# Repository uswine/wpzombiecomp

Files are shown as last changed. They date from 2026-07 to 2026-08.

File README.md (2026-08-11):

# Offset Smoker — Door Spring-Hinge Assembly

Design proposal for the main cook-chamber doors: a **cam-detent snap-close** combined
with **coiled-ribbon (power spring) lift assist**, with all spring hardware mounted
outboard of the shell behind a heat shield.

Behavior over the 90° door travel:
- **0–15°** — cam detent pulls the door shut with authority and holds it sealed
- **15–88°** — ribbon springs carry ~73% of the door weight (peak hand effort ~11 lb
  instead of 37 lb on the worked example)
- **88–90°** — a shallow second cam notch parks the door vertical

| File | Contents |
|---|---|
| [`docs/PHONE-SETUP.md`](docs/PHONE-SETUP.md) | How to run Claude Code sessions on this repo from a phone, and how to create new repositories for it |
| [`docs/DESIGN.md`](docs/DESIGN.md) | Full proposal: concept, torque analysis, component specs, tuning procedure, alternatives comparison |
| [`drawings/`](drawings/) | Blueprint sheets 1–4: assembly end view, snap cam detail, spring canister section, torque-balance chart |
| [`calculator.html`](calculator.html) | Interactive sizing calculator — re-solves springs, cam, and stall check for your actual chamber/door dimensions (works offline) |
| [`tools/generate_drawings.py`](tools/generate_drawings.py) | Generates the SVG sheets from the design parameters |
| [`docs/PLATE-OPTIMIZATION.md`](docs/PLATE-OPTIMIZATION.md) | Rotary damper plates (Rev B): sealing rules, architecture trade study, optimization record |
| [`drawings/plate-24-perforated.*`](drawings/) | Waterjet fabrication print (SVG/PDF) + cut-ready DXF — Ø24 damper plate, QTY 2 identical |
| [`tools/generate_plate_drawing.py`](tools/generate_plate_drawing.py) | Generates the damper plate print and DXF |
| [`drawings/pizza-plate-24.*`](drawings/) | 24" pizza cooking plate (vertical smoker): fab print (SVG/PDF), single-contour DXF, STL solid |
| [`mail-sender/`](mail-sender/) | Outbound email API for Claude sessions: send as ahall@zombiecomponents.com via Microsoft Graph (app-only flow, one-mailbox scoped) |
| [`tools/generate_pizza_plate.py`](tools/generate_pizza_plate.py) | Parametric generator for the pizza plate (contour, DXF, STL, print) |

The worked example assumes a 24" OD × ¼"-wall chamber with a 120° × 30" top-hinged
door; every number is parametric — see `docs/DESIGN.md` §4 or plug real dimensions
into the calculator.

Sheet 1 — Assembly

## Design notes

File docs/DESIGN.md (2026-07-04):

# Offset Smoker — Door Spring-Hinge Assembly
### Cam-detent snap-close + coiled ribbon (power spring) lift assist

**Status:** Design proposal for review
**Drawings:** `drawings/sheet1-assembly.svg` … `sheet4-torque.svg`
**Sizing tool:** `calculator.html` (open in any browser, works offline)

> **Note on dimensions.** The earlier blueprint work isn't in this repository, so the
> worked example below assumes a typical 24" OD × ¼"-wall pipe cook chamber with a
> 120°-arc × 30"-long top-hinged door (~60 lb). Every number derives from the formulas
> in §4, and `calculator.html` re-solves the whole design for your actual chamber
> diameter, door arc, and door length — plug in the real blueprint dimensions and it
> outputs the spring and cam specs directly.

---

## 1. What the mechanism does

Three distinct behaviors over the 90° door travel, exactly as requested:

| Zone | Door angle | Behavior | What provides it |
|---|---|---|---|
| **Snap zone** | 0°–15° | Door is pulled shut with authority and held sealed (~105 in·lb net closing at the seat) | Cam detent valley + spring-loaded roller follower |
| **Assist zone** | 15°–88° | Ribbon springs carry ~70–75% of the door weight; peak hand effort ≈ **11 lb** instead of **37 lb** bare | Two power-spring canisters on the hinge shaft |
| **Hold-open** | 88°–90° | Door parks vertical with ~2× holding margin; a light tug releases it | Shallow second notch in the same cam |

The key idea is **decoupling**: the ribbon springs provide a nearly flat counterbalance
torque across the whole swing, and the cam detent provides the over-center snap
*only* in the last 15°. Each is tuned independently — follower spring preload sets the
slam/seal force, ribbon spring preload sets how light the door feels. A single spring
trying to do both jobs can't, because the two behaviors want opposite torque signs
near closed.

## 2. Architecture (per door)

```
                        [cook chamber, end view]
   heat shield ─┐            ┌─ standoff bracket (2" air gap)
                ▼            ▼
  ┌────────────────────────────────────────────────────────────┐
  │  LEFT SHAFT END              HINGE LINE              RIGHT  │
  │  power-spring canister   1" shaft in 3 bronze-      power-  │
  │  + preload ratchet       bushed weld-on bosses      spring  │
  │  + SNAP CAM & follower                              canister│
  └────────────────────────────────────────────────────────────┘
```

- **Hinge shaft** — 1.000" CRS (4140 preferred) running the full door width plus 3"
  past each end. The door is welded to the shaft through two gusseted straps, so
  *door and shaft rotate together*. Shaft rides in three weld-on DOM bosses with
  graphite-plugged bronze bushings (no grease to cook off).
- **Power-spring canisters (×2)** — one on each shaft end. Coiled ribbon spring
  (the type in your reference photo, scaled up): inner end keyed to an arbor on the
  shaft, outer end hooked to the case. The case sits in a bracket collar with
  **ratchet teeth on its OD and a pawl on the bracket** — preload is adjusted with a
  spanner in one-tooth clicks, no disassembly, exactly like winding a recoil starter.
- **Snap cam** — a 5" Ø × ½" profiled disc keyed to the left shaft end. A 1.5" cam
  follower roller on a pivot arm, loaded by a 120 lb die spring on the bracket,
  rides the cam. The valley at 0° creates the snap; the shallow notch at 88° is the
  hold-open. Between them the cam is a constant-radius dwell → zero cam torque, so
  the assist zone feels pure spring.
- **Everything outboard** — canisters, cam, and follower all hang on standoff
  brackets 2" off the shell with a polished 16-ga 304 stainless radiation shield in
  the gap. Nothing but the shaft and bosses touches hot steel.

## 3. Why it behaves the way you asked

Torque about the hinge, opening positive (worked example, full curves on Sheet 4):

| θ | Gravity | Springs | Cam | **Net** | Hand @ 20" handle |
|---:|---:|---:|---:|---:|---:|
| 0° | −449 | +550 | −206 | **−105** | held shut |
| 6° | −507 | +546 | −124 | **−85** | pulls itself closed |
| 15° | −584 | +541 | 0 | **−43** | crossover — spring takes over |
| 52° | −734 | +518 | 0 | **−216** | 10.9 lb (37 lb unassisted) |
| 90° | −581 | +495 | 0 | **−86** | held by 172 in·lb notch |

Note the net torque is **monotonically closing through the entire snap zone** — this
took one design iteration to get right. With a 12° linear ramp the fading detent
crossed under the spring surplus at ~9° and the door would have hung there instead of
snapping shut. The fix is a 15° ramp with 0.45" valley depth, which keeps ≥30 in·lb
of closing margin at every angle in the zone. **If you rescale the design, re-check
this with the calculator — it flags a stall automatically.**

Failure mode is benign: if a ribbon spring ever breaks, you simply have a heavy door
again — the hinge still works and the cam still snaps it shut.

## 4. Sizing math (what the calculator implements)

**Door weight & CG.** For a door of arc angle 2α on a chamber of radius R,
length D, plate thickness t: W = R·(2α)·D·t·0.284 + hardware. The CG sits on the arc
bisector at radius r = R·sin α / α.

**Gravity torque.** With hinge pin at position **H** (just off the shell above the
door's top edge) and CG at **G**: L = |HG|, β = angle of H→G below horizontal at
closed. Then T_g(θ) = W·L·cos(θ − β), closing. For the example: W·L = 735 in·lb,
β = 52.3°. Gravity peaks mid-swing (θ = β) — this is why a flat spring curve is the
right counterbalance shape.

**Ribbon springs.** Torque per spring M = k·(n_preload − θ/360). Rate
k = 2πE·I / L_ribbon with I = b·t³/12. Bending stress σ = 6M/(b·t²); keep ≤150 ksi
for chrome-silicon (fatigue life is effectively unlimited at our 0.25-turn working
stroke).

**Cam detent.** Energy method: T_detent = F_follower × (valley depth / ramp angle in
radians). Snap-through requires T_detent(θ) > T_spring(θ) − T_gravity(θ) for all θ in
the ramp.

## 5. Worked-example specification

| Item | Spec |
|---|---|
| Ribbon spring (×2) | Chrome-silicon or 17-7 PH ribbon, **2.00" × 0.085" × 175" (14.6 ft)**, k ≈ 110 in·lb/turn, wound on 1.25" arbor |
| Canister | 6.5" case ID × 7.0" OD × 2.25" internal width, 12-ga case, bolted cover, ratchet teeth on OD |
| Nominal preload | **2.5 turns per spring** (550 in·lb total at closed, σ = 114 ksi) |
| Preload hard limit | **3.25 turns** (σ = 150 ksi) — stamp on the case |
| Snap cam | 5.00" Ø × ½" plate, 2.50" base radius, valley **0.45" deep over 15°**, hold-open notch 0.20" over 8° centered at 88°, stop tab at 93°, 1.000" bore + ¼" keyway |
| Follower | 1.5" Ø cam follower roller on 4" pivot arm, 1" OD × 2.5" medium die spring preloaded to **120 lb** with adjuster bolt |
| Shaft | 1.000" × 40" CRS/4140, ¼" keyways both ends |
| Bushings | Graphite-plugged bronze, 1.00" ID in 1.50" OD DOM weld bosses (×3) |
| Brackets | 3/16" plate standoffs, 2.0" air gap, 16-ga 304 polished heat shield |

### Tuning procedure
1. Door welded and hung, springs relaxed: verify free swing and that the cam roller
   seats in the valley at full close.
2. Wind each canister to 2.5 turns (ratchet clicks are marked on the case).
3. Lift test: door should take roughly 10–12 lb at the handle mid-swing and stay put
   at vertical. Too heavy → +1 click each side, alternating. Pops open at the seat or
   won't snap the last few degrees → back off, or add follower preload instead.
4. Slam check: release from 30°; door must accelerate through the snap zone and seat
   with a thunk, no hesitation.

### ⚠ Stored-energy safety
A wound canister stores real energy (~250 J each at full preload). Each case gets a
**keeper-pin hole** that locks arbor to case for assembly/service — pin in before any
bracket bolt comes out. Wind only with the spanner, never fingers on the ratchet ring.

## 6. Heat management

Outside-shell skin near the door runs roughly 250–400 °F on a hard fire. Spring
temper starts degrading above ~350 °F for music wire, so:
- **Material:** chrome-silicon (good to ~475 °F) or 17-7 PH stainless ribbon — not
  plain blued clock-spring steel.
- **Standoff + shield:** the 2" air gap with a polished stainless shield between
  shell and canister keeps the spring pack under ~200 °F, well inside its rating.
- **Bushings:** graphite-plugged bronze — nothing to melt or cook off; a dab of
  copper anti-seize on the keyways at assembly.

## 7. Alternatives considered — and my recommendation

| Option | Snap-close? | Assist quality | Heat | Verdict |
|---|---|---|---|---|
| **Ribbon power spring + snap cam** (this design) | ✅ crisp, tunable | ✅ near-flat curve, click-adjustable | ✅ with standoff | **Primary recommendation** |
| Helical torsion spring on the hinge line (garage-door stock) + same cam | ✅ same cam | ✅ nearly identical | ✅ | **Best budget fallback** — see below |
| Gas struts | ❌ (fights closing) | ✅ | ❌ seals die ~175 °F | Rejected |
| Counterweight arm | ❌ can't snap | ✅ never wears out | ✅ | The classic, but no snap and a head-height swing hazard |
| Cable + extension spring on a spiral drum | ✅ (drum profile) | ✅ most shapeable curve | ✅ | Works, but the most exposed clutter and a cable to fray |

Honest sourcing note: 250 in·lb-class power springs are **custom-order** parts
(Vulcan Spring, John Evans' Sons, etc. — a few weeks and real money for two). If that
becomes a hassle, the drop-in alternative keeps *everything* in this design — shaft,
cam, follower, brackets, behavior — and swaps each canister for a ~12" length of
off-the-shelf garage-door torsion spring (0.243" wire × 2" ID stock ≈ 39 in·lb/turn;
wound ~3.5 turns via a plain anchor collar) sleeved in a guard tube on the same shaft.
You lose the beautiful coiled-ribbon look and the one-click ratchet adjustment; you
gain ~$60 hardware-store parts. Mechanically they are equivalent here because our
working stroke is only a quarter turn.

So: the mechanism you proposed is genuinely the right one for the feel you described —
the cam gives it the snap a counterweight never can, and the ribbon spring gives the
flattest assist curve of anything that survives the heat. I'd build it as drawn, with
the garage-spring variant in your back pocket if the custom spring quote comes back
ugly.

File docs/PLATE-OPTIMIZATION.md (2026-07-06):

# Rotary Damper Plates — Design & Optimization Record (Rev E)

**Part:** WPZ-PLT-001 Rev E — Ø24.00 × .375 A36, waterjet cut, **QTY 2 identical**
**Print:** `drawings/plate-24-perforated.svg` / `.pdf` · **CAM geometry:** `drawings/plate-24-perforated.dxf`

## Rev E — center pivot hole added (current)

Ø0.500 thru hole at plate center on both plates for the pivot bolt/axle. The
bolt fills it, so it adds no leak path; hub ring remains solid otherwise.

## Rev D — half-diameter edge gap

Review corrections applied in sequence: (Rev C) outer-row holes 2–3× the Rev B
Ø1.740 via per-row diameters; (Rev D) the OD-to-hole gap scales with hole size —
**gap ≥ 0.5 × the row-1 hole diameter**, not a flat 0.500". Same hole count per
row (5 spokes) preserves single-angle shutoff and monotonic flow.

With gap = D/2 the outer row solves to: r₁ = 12 − D₁, and the in-row spacing rule
2πr₁/5 ≥ 2.5·D₁ caps D₁ at 4.014 → **Ø4.000 at R8.000** (gap exactly 2.000).

| Parameter | Value |
|---|---|
| Pattern | **5 spokes × 2 rows: Row 1 = 5 × Ø4.000 at R8.000, Row 2 = 5 × Ø1.500 at R3.000** |
| Outer row vs Rev B | Ø4.000 = **2.30×** Ø1.740 |
| OD-to-hole gap | **2.000 = 0.5×Ø exact** |
| Spacing | Row 1 c-c 10.053 (2.51×Ø), Row 2 c-c 3.770 (2.51×Ø), radial web 2.250 (1.5× row-2 Ø) |
| Shutoff twist | **36.0°** (= 180/5) |
| Flow vs twist | 9°=61%, 18°=26%, 27°=2%, 36°=0% — monotonic (verified) |
| Closed seal cover | **0.354" minimum** over all fixed-vs-rotated pairs |
| Open area (aligned) | **71.7 in² = 15.8%** (Rev B 42.8 → Rev C 94.4 → Rev D 71.7) |
| Hub | inner hole edge at R2.250 vs hub R1.750 → 0.500 clear |
| Weight | 40.5 lb per plate |

---

# Rev B record (superseded)

## What changed from Rev A and why

Rev A optimized a single perforated plate at 1.333×Ø spacing (60 holes, 41.7% open).
Design review corrected the intent: **two identical plates stacked, one rotating**
— a rotary damper. That kills Rev A twice over:

1. **Sealing.** At 1.333×Ø spacing the web between holes (0.333×Ø) is far narrower
   than a hole, so the rotated plate's holes can never land fully on solid metal —
   the damper cannot shut off. Rule adopted: **web = 1.5×Ø minimum (c-c = 2.5×Ø)**.
   At the closed position each hole then sits centered in a web with real cover on
   both sides.
2. **Common shutoff angle.** A row with n holes seals at a twist of 180/n. Rev A's
   24/18/12/6 rows would seal at 7.5°/10°/15°/30° — no single lever position closes
   them all. Every row must share one closure angle.

## Architecture selection

Candidates evaluated (all with c-c = 2.5×Ø, 0.50" edge margin, Ø3.5 solid hub):

| Architecture | Shutoff | Flow behavior | Best open area |
|---|---|---|---|
| Mixed counts, odd-multiple family (21/15/9 etc.) | ✅ one angle | ❌ **non-monotonic** — flow re-opens to 67% mid-travel | 56.6 in² |
| **Same count every row (radial spokes)** | ✅ one angle | ✅ **monotonic 100%→0%** | **42.8 in²** |
| Single ring, few large holes (daisy) | ✅ | ✅ monotonic | 55–75 in² |

The mixed-count family was rejected on the measured flow curve: between open and
closed the total flow oscillates wildly (7% at 9° twist, back to 67% at 51°),
making the lever position meaningless. Same-count spokes are the classic rotary
damper solution and were selected. The daisy option (e.g. 6 × Ø3.98 = 74.6 in²)
flows most but abandons the multi-row distribution; noted as an alternative if
the damper feeds a plenum where distribution doesn't matter.

## Optimized result (same-count architecture)

Sweep over hole diameter with rows placed inward at 2.5×Ø pitch until the hub
stops the next row; hole count set by the inner row; open area maximized:

**Ø1.740 holes — 18 total on 9 radial spokes × 2 rows (R10.630 / R6.280).**
The raw optimum was Ø1.747, but that fits the 9th hole with 0.003" of spacing
margin; Ø1.740 restores a healthy margin (inner-row web = 1.52×Ø).

| Parameter | Value |
|---|---|
| Hole diameter | Ø1.740 (18 plcs) |
| Row radii / counts | R10.630 × 9, R6.280 × 9 (spokes aligned, first hole at 0°) |
| Spacing | row pitch 4.350 (2.50×Ø exact); in-row c-c 4.384 min (2.52×Ø) |
| Shutoff twist | **20.0°** (= 180/9) |
| Flow vs twist | 0°=100%, 5°=74%, 10°=41%, 15°=13%, 20°=0% — monotonic (verified) |
| Closed-position seal cover | **0.441" minimum**, verified over all fixed-vs-rotated hole pairs |
| Open area (aligned) | 42.8 in² = 9.5% of gross |
| Edge margin / hub | 0.500" exact / inner hole edge at R5.41, hub untouched |
| Weight | 43.6 lb per plate (87 lb pair) |

A third row does not fit: the next row would sit at R1.93, inside the hub limit
of R2.62 — satisfying "rows continue inward until no additional holes fit."

## Notes for the build

- Plates are cut from the **same DXF** — no left/right handing.
- Deburr both faces; the plates must rotate flush against each other to seal.
- The 20° control span maps nicely to a short lever slot; add end stops at 0°
  and 20° so the operator can't over-travel into the next opening cycle.
- If more open area is ever needed: 1 ring of 9 × Ø2.80 gives 55.4 in² and the
  6 × Ø3.98 daisy gives 74.6 in², both rule-compliant and monotonic — at the cost
  of concentrating flow at one radius.

Regenerate print + DXF with `python3 tools/generate_plate_drawing.py`.

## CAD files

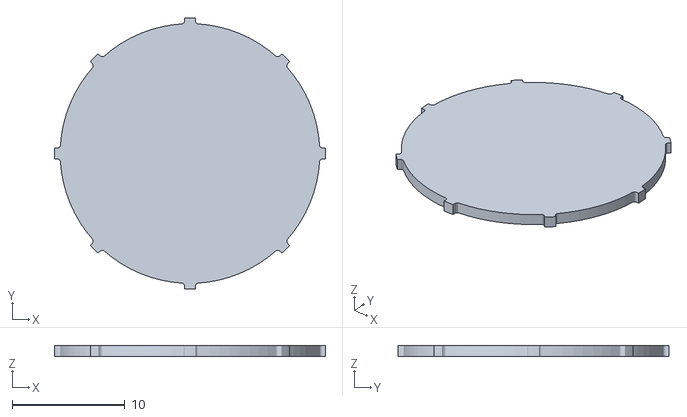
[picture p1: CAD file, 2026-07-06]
drawings/pizza-plate-24.stl
24.0 x 24.0 x 1.00

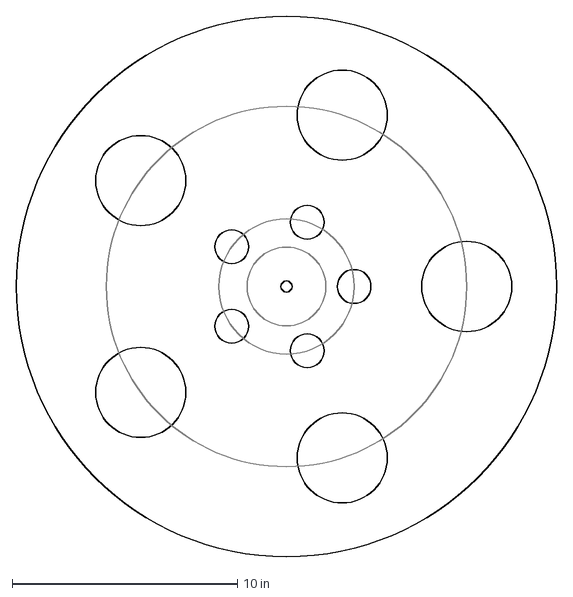
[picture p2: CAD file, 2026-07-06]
drawings/plate-24-perforated.dxf
24.0 x 24.0 in

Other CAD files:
drawings/pizza-plate-24.dxf

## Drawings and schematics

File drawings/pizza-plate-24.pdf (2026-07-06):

# 24" PIZZA COOKING PLATE — VERTICAL OFFSET SMOKER

## 1) TOP VIEW (PLAN) — GOVERNING

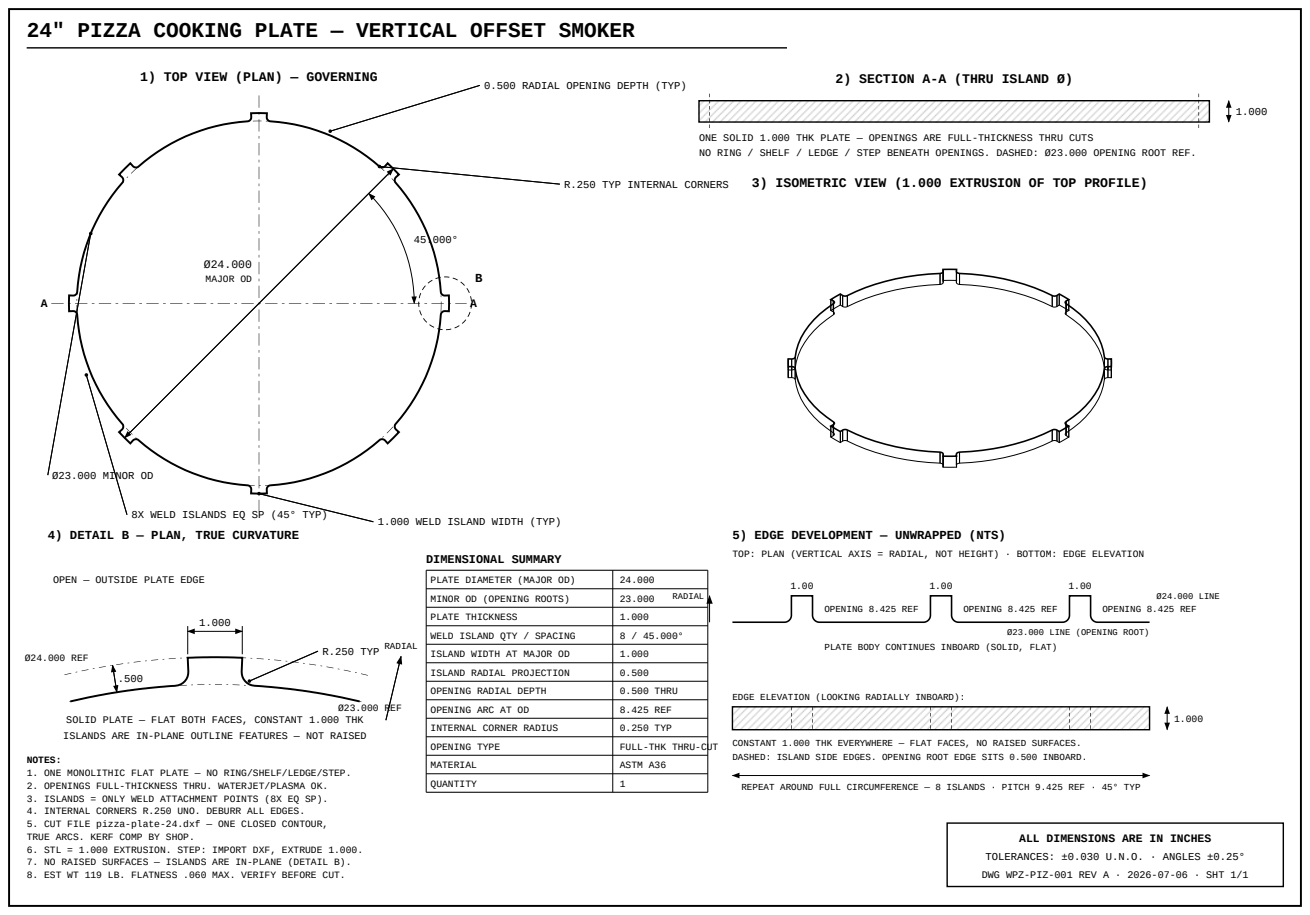
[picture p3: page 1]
Ø24.000 MAJOR OD; Ø23.000 MINOR OD; Ø24.000 REF; Ø23.000 REF; R.250 TYP; RADIAL; OPENING 8.425 REF; Ø24.000 LINE; DIMENSIONAL SUMMARY; OPENING TYPE; FULL-THK THRU-CUT

2) SECTION A-A (THRU ISLAND Ø)

0.500 RADIAL OPENING DEPTH (TYP)

ONE SOLID 1.000 THK PLATE — OPENINGS ARE FULL-THICKNESS THRU CUTS
NO RING / SHELF / LEDGE / STEP BENEATH OPENINGS. DASHED: Ø23.000 OPENING ROOT REF.

3) ISOMETRIC VIEW (1.000 EXTRUSION OF TOP PROFILE)

R.250 TYP INTERNAL CORNERS

8X WELD ISLANDS EQ SP (45° TYP)

1.000 WELD ISLAND WIDTH (TYP)

4) DETAIL B — PLAN, TRUE CURVATURE

5) EDGE DEVELOPMENT — UNWRAPPED (NTS)
TOP: PLAN (VERTICAL AXIS = RADIAL, NOT HEIGHT) · BOTTOM: EDGE ELEVATION

OPEN — OUTSIDE PLATE EDGE

PLATE DIAMETER (MAJOR OD) | 24.000
MINOR OD (OPENING ROOTS) | 23.000 RADIAL
PLATE THICKNESS | 1.000
WELD ISLAND QTY / SPACING | 8 / 45.000°
ISLAND WIDTH AT MAJOR OD | 1.000
ISLAND RADIAL PROJECTION | 0.500
OPENING RADIAL DEPTH | 0.500 THRU
OPENING ARC AT OD | 8.425 REF
INTERNAL CORNER RADIUS | 0.250 TYP

Ø23.000 LINE (OPENING ROOT)

PLATE BODY CONTINUES INBOARD (SOLID, FLAT)

EDGE ELEVATION (LOOKING RADIALLY INBOARD):

SOLID PLATE — FLAT BOTH FACES, CONSTANT 1.000 THK
ISLANDS ARE IN-PLANE OUTLINE FEATURES — NOT RAISED

CONSTANT 1.000 THK EVERYWHERE — FLAT FACES, NO RAISED SURFACES.
DASHED: ISLAND SIDE EDGES. OPENING ROOT EDGE SITS 0.500 INBOARD.

NOTES:
1. ONE MONOLITHIC FLAT PLATE — NO RING/SHELF/LEDGE/STEP.
2. OPENINGS FULL-THICKNESS THRU. WATERJET/PLASMA OK.
3. ISLANDS = ONLY WELD ATTACHMENT POINTS (8X EQ SP).
4. INTERNAL CORNERS R.250 UNO. DEBURR ALL EDGES.
5. CUT FILE pizza-plate-24.dxf — ONE CLOSED CONTOUR,
TRUE ARCS. KERF COMP BY SHOP.
6. STL = 1.000 EXTRUSION. STEP: IMPORT DXF, EXTRUDE 1.000.
7. NO RAISED SURFACES — ISLANDS ARE IN-PLANE (DETAIL B).
8. EST WT 119 LB. FLATNESS .060 MAX. VERIFY BEFORE CUT.

MATERIAL | ASTM A36
QUANTITY | 1

REPEAT AROUND FULL CIRCUMFERENCE — 8 ISLANDS · PITCH 9.425 REF · 45° TYP

ALL DIMENSIONS ARE IN INCHES
TOLERANCES: ±0.030 U.N.O. · ANGLES ±0.25°
DWG WPZ-PIZ-001 REV A · 2026-07-06 · SHT 1/1

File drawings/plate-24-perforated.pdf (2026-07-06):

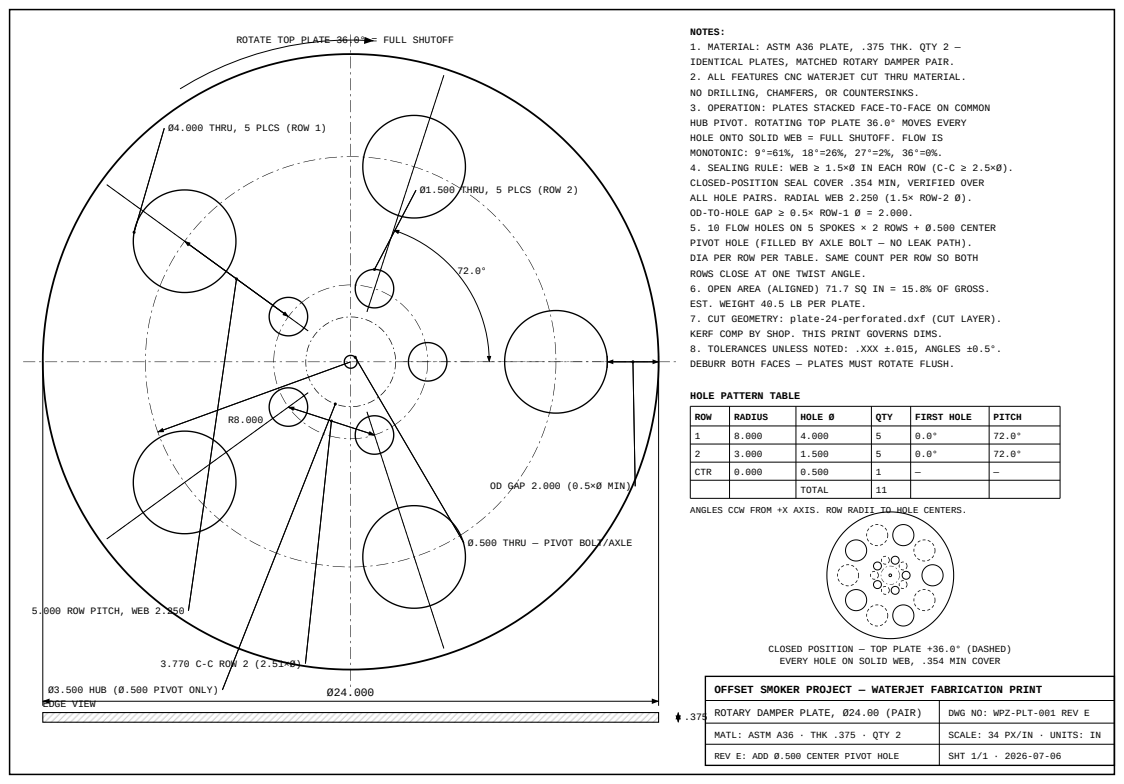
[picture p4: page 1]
3.770 C-C ROW 2 (2.51×Ø); ROTARY DAMPER PLATE, Ø24.00 (PAIR); DWG NO: WPZ-PLT-001 REV E; MATL: ASTM A36 · THK .375 · QTY 2; SCALE: 34 PX/IN · UNITS: IN; REV E: ADD Ø.500 CENTER PIVOT HOLE; SHT 1/1 · 2026-07-06

NOTES:
1. MATERIAL: ASTM A36 PLATE, .375 THK. QTY 2 —
IDENTICAL PLATES, MATCHED ROTARY DAMPER PAIR.
2. ALL FEATURES CNC WATERJET CUT THRU MATERIAL.
NO DRILLING, CHAMFERS, OR COUNTERSINKS.
3. OPERATION: PLATES STACKED FACE-TO-FACE ON COMMON
HUB PIVOT. ROTATING TOP PLATE 36.0° MOVES EVERY
HOLE ONTO SOLID WEB = FULL SHUTOFF. FLOW IS
MONOTONIC: 9°=61%, 18°=26%, 27°=2%, 36°=0%.
4. SEALING RULE: WEB ≥ 1.5×Ø IN EACH ROW (C-C ≥ 2.5×Ø).
CLOSED-POSITION SEAL COVER .354 MIN, VERIFIED OVER
ALL HOLE PAIRS. RADIAL WEB 2.250 (1.5× ROW-2 Ø).
OD-TO-HOLE GAP ≥ 0.5× ROW-1 Ø = 2.000.
5. 10 FLOW HOLES ON 5 SPOKES × 2 ROWS + Ø.500 CENTER
PIVOT HOLE (FILLED BY AXLE BOLT — NO LEAK PATH).
DIA PER ROW PER TABLE. SAME COUNT PER ROW SO BOTH
ROWS CLOSE AT ONE TWIST ANGLE.
6. OPEN AREA (ALIGNED) 71.7 SQ IN = 15.8% OF GROSS.
EST. WEIGHT 40.5 LB PER PLATE.
7. CUT GEOMETRY: plate-24-perforated.dxf (CUT LAYER).
KERF COMP BY SHOP. THIS PRINT GOVERNS DIMS.
8. TOLERANCES UNLESS NOTED: .XXX ±.015, ANGLES ±0.5°.
DEBURR BOTH FACES — PLATES MUST ROTATE FLUSH.

ROTATE TOP PLATE 36.0° = FULL SHUTOFF

Ø4.000 THRU, 5 PLCS (ROW 1)

Ø1.500 THRU, 5 PLCS (ROW 2)

HOLE PATTERN TABLE

ROW | RADIUS | HOLE Ø | QTY | FIRST HOLE | PITCH
1 | 8.000 | 4.000 | 5 | 0.0° | 72.0°
2 | 3.000 | 1.500 | 5 | 0.0° | 72.0°
CTR | 0.000 | 0.500 | 1 | — | —

OD GAP 2.000 (0.5×Ø MIN)

TOTAL | 11

ANGLES CCW FROM +X AXIS. ROW RADII TO HOLE CENTERS.

Ø.500 THRU — PIVOT BOLT/AXLE

5.000 ROW PITCH, WEB 2.250

CLOSED POSITION — TOP PLATE +36.0° (DASHED)
EVERY HOLE ON SOLID WEB, .354 MIN COVER

Ø3.500 HUB (Ø.500 PIVOT ONLY)
EDGE VIEW

OFFSET SMOKER PROJECT — WATERJET FABRICATION PRINT

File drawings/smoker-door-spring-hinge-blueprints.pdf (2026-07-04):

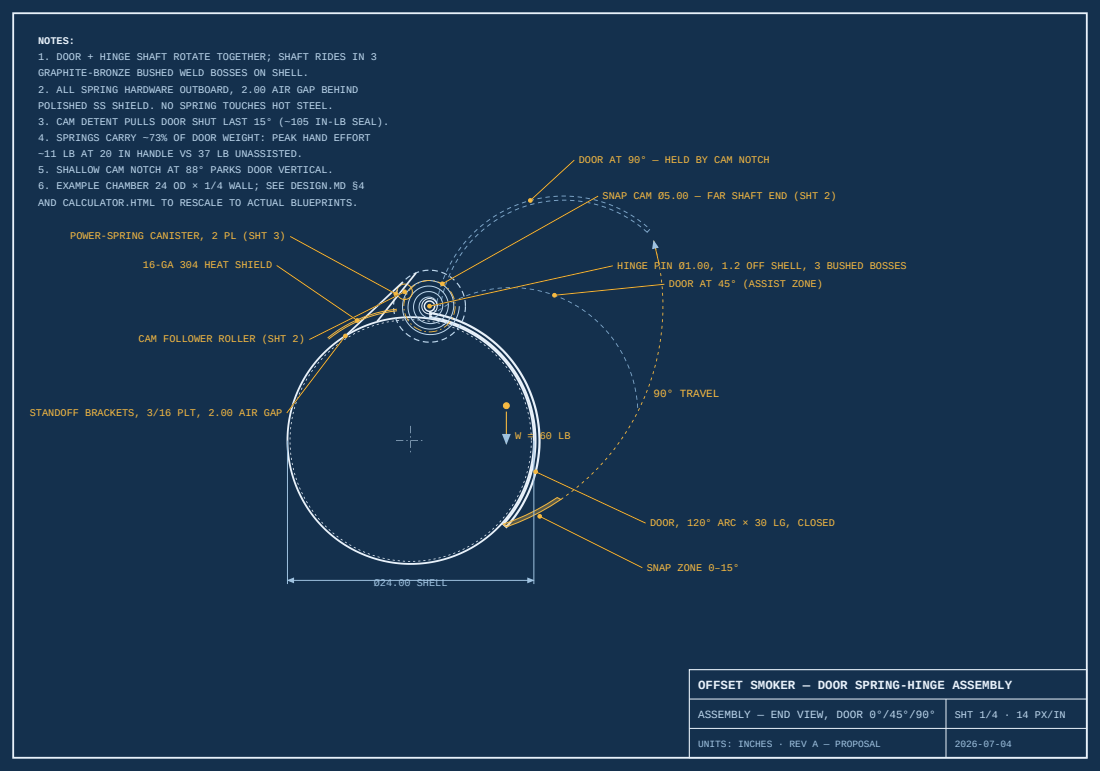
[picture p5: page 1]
90° TRAVEL; SNAP ZONE 0–15°; Ø24.00 SHELL

NOTES:
1. DOOR + HINGE SHAFT ROTATE TOGETHER; SHAFT RIDES IN 3
GRAPHITE-BRONZE BUSHED WELD BOSSES ON SHELL.
2. ALL SPRING HARDWARE OUTBOARD, 2.00 AIR GAP BEHIND
POLISHED SS SHIELD. NO SPRING TOUCHES HOT STEEL.
3. CAM DETENT PULLS DOOR SHUT LAST 15° (~105 IN-LB SEAL).
4. SPRINGS CARRY ~73% OF DOOR WEIGHT: PEAK HAND EFFORT
~11 LB AT 20 IN HANDLE VS 37 LB UNASSISTED.
5. SHALLOW CAM NOTCH AT 88° PARKS DOOR VERTICAL.
6. EXAMPLE CHAMBER 24 OD × 1/4 WALL; SEE DESIGN.MD §4
AND CALCULATOR.HTML TO RESCALE TO ACTUAL BLUEPRINTS.

DOOR AT 90° — HELD BY CAM NOTCH

SNAP CAM Ø5.00 — FAR SHAFT END (SHT 2)

POWER-SPRING CANISTER, 2 PL (SHT 3)

16-GA 304 HEAT SHIELD

HINGE PIN Ø1.00, 1.2 OFF SHELL, 3 BUSHED BOSSES

DOOR AT 45° (ASSIST ZONE)

CAM FOLLOWER ROLLER (SHT 2)

STANDOFF BRACKETS, 3/16 PLT, 2.00 AIR GAP

DOOR, 120° ARC × 30 LG, CLOSED

OFFSET SMOKER — DOOR SPRING-HINGE ASSEMBLY

ASSEMBLY — END VIEW, DOOR 0°/45°/90°

SHT 1/4 · 14 PX/IN

UNITS: INCHES · REV A — PROPOSAL

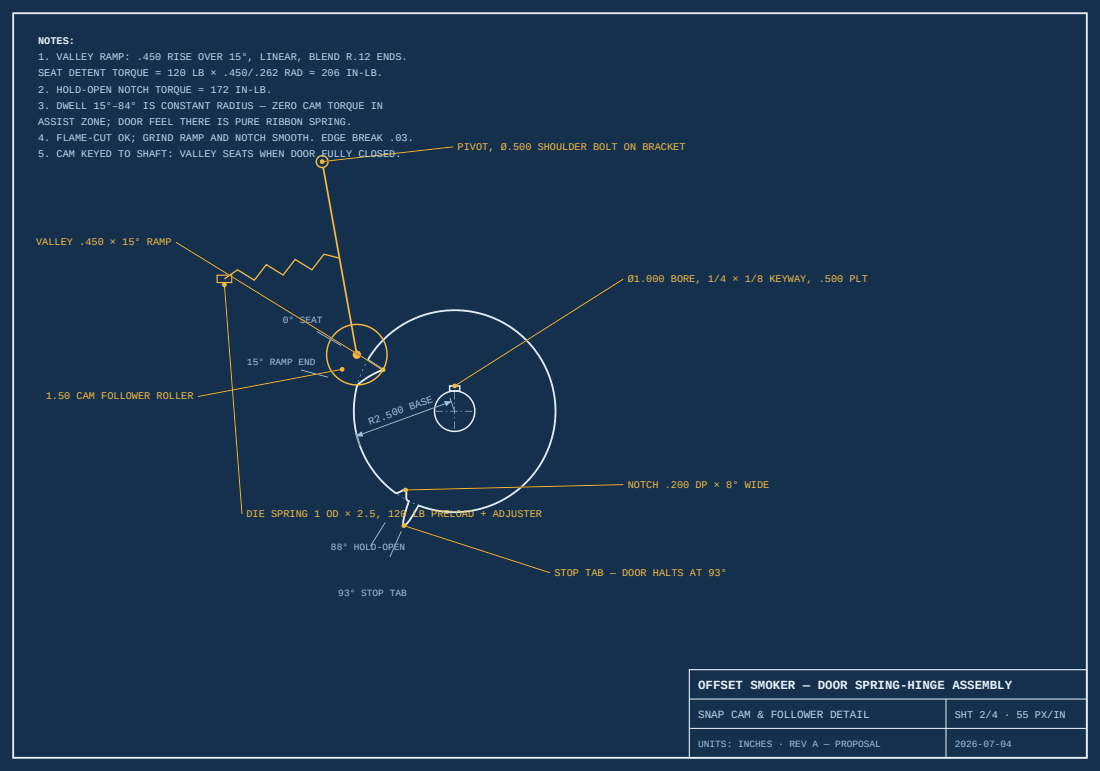
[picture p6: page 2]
0° SEAT; 15° RAMP END; 88° HOLD-OPEN; 93° STOP TAB; R2.500 BASE; VALLEY .450 × 15° RAMP

NOTES:
1. VALLEY RAMP: .450 RISE OVER 15°, LINEAR, BLEND R.12 ENDS.
SEAT DETENT TORQUE = 120 LB × .450/.262 RAD ≈ 206 IN-LB.
2. HOLD-OPEN NOTCH TORQUE ≈ 172 IN-LB.
3. DWELL 15°–84° IS CONSTANT RADIUS — ZERO CAM TORQUE IN
ASSIST ZONE; DOOR FEEL THERE IS PURE RIBBON SPRING.
4. FLAME-CUT OK; GRIND RAMP AND NOTCH SMOOTH. EDGE BREAK .03.
5. CAM KEYED TO SHAFT: VALLEY SEATS WHEN DOOR FULLY CLOSED.

PIVOT, Ø.500 SHOULDER BOLT ON BRACKET

Ø1.000 BORE, 1/4 × 1/8 KEYWAY, .500 PLT

1.50 CAM FOLLOWER ROLLER

NOTCH .200 DP × 8° WIDE

DIE SPRING 1 OD × 2.5, 120 LB PRELOAD + ADJUSTER

STOP TAB — DOOR HALTS AT 93°

OFFSET SMOKER — DOOR SPRING-HINGE ASSEMBLY

SNAP CAM & FOLLOWER DETAIL

SHT 2/4 · 55 PX/IN

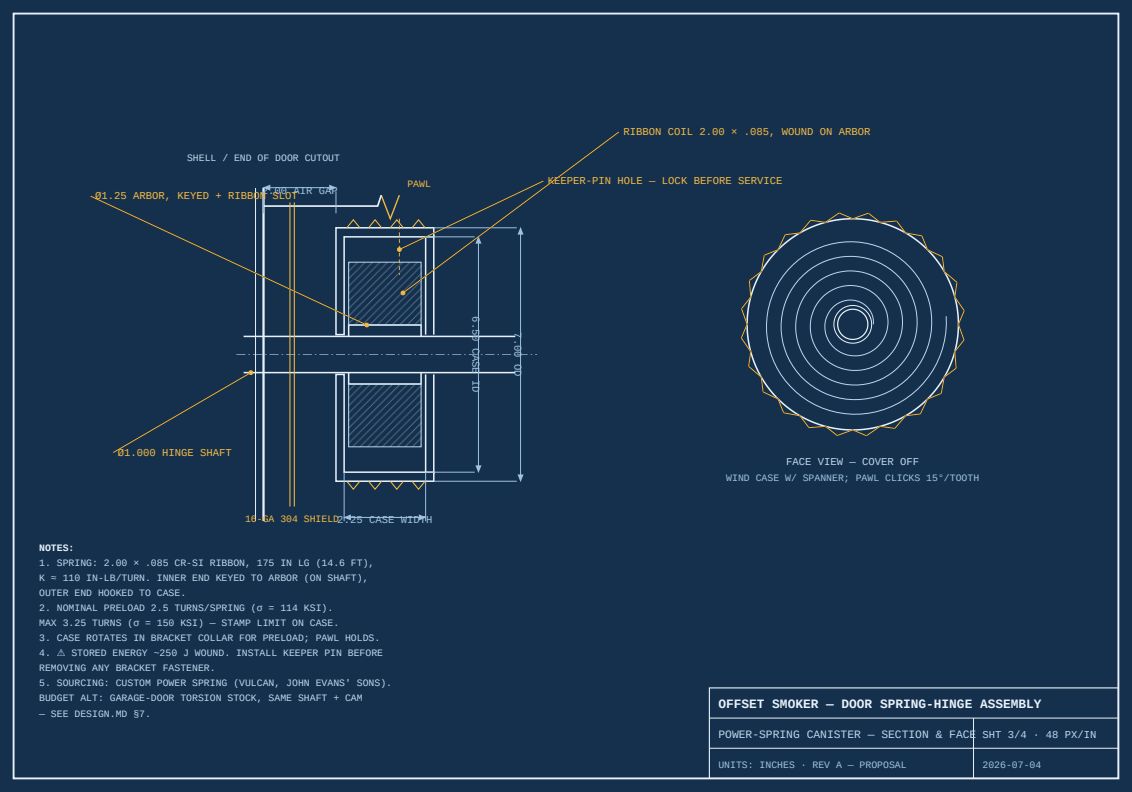
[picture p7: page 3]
PAWL; 16-GA 304 SHIELD; 2.25 CASE WIDTH; 2.00 AIR GAP; Ø1.000 HINGE SHAFT

RIBBON COIL 2.00 × .085, WOUND ON ARBOR

SHELL / END OF DOOR CUTOUT

KEEPER-PIN HOLE — LOCK BEFORE SERVICE

Ø1.25 ARBOR, KEYED + RIBBON SLOT

FACE VIEW — COVER OFF

WIND CASE W/ SPANNER; PAWL CLICKS 15°/TOOTH

NOTES:
1. SPRING: 2.00 × .085 CR-SI RIBBON, 175 IN LG (14.6 FT),
K ≈ 110 IN-LB/TURN. INNER END KEYED TO ARBOR (ON SHAFT),
OUTER END HOOKED TO CASE.
2. NOMINAL PRELOAD 2.5 TURNS/SPRING (σ = 114 KSI).
MAX 3.25 TURNS (σ = 150 KSI) — STAMP LIMIT ON CASE.
3. CASE ROTATES IN BRACKET COLLAR FOR PRELOAD; PAWL HOLDS.
4. ⚠ STORED ENERGY ~250 J WOUND. INSTALL KEEPER PIN BEFORE
REMOVING ANY BRACKET FASTENER.
5. SOURCING: CUSTOM POWER SPRING (VULCAN, JOHN EVANS' SONS).
BUDGET ALT: GARAGE-DOOR TORSION STOCK, SAME SHAFT + CAM
— SEE DESIGN.MD §7.

OFFSET SMOKER — DOOR SPRING-HINGE ASSEMBLY

POWER-SPRING CANISTER — SECTION & FACE

SHT 3/4 · 48 PX/IN

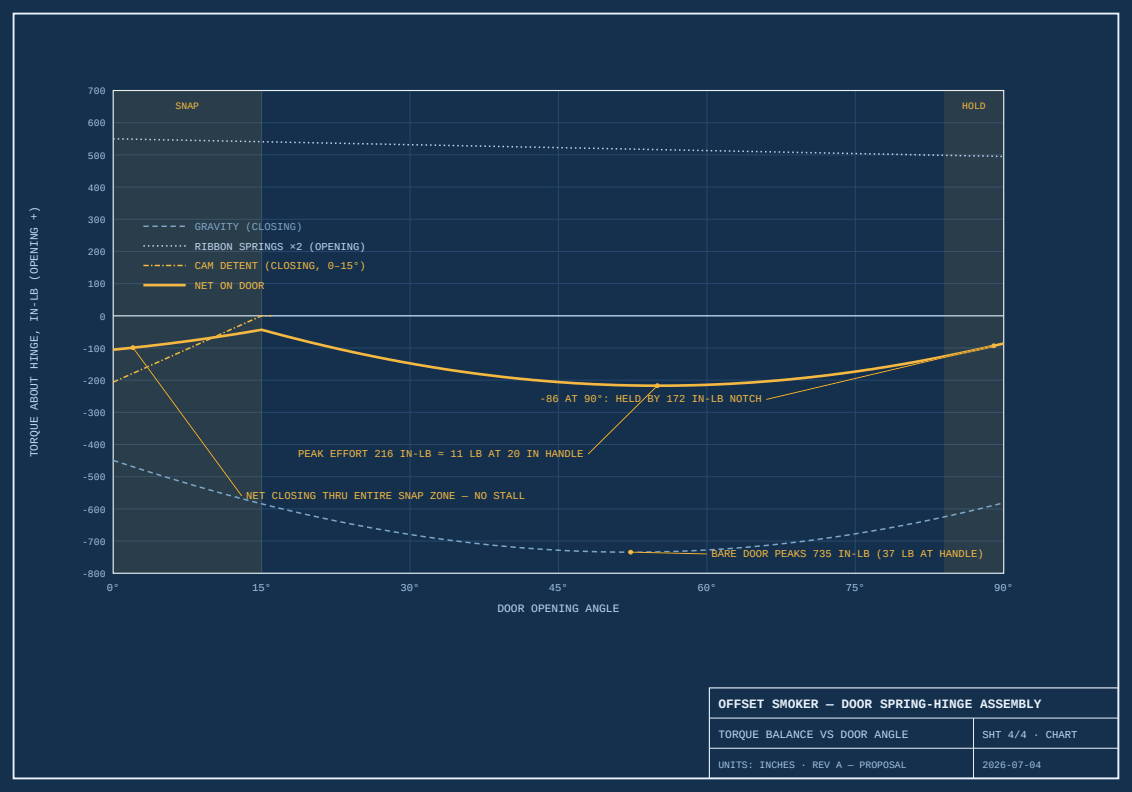
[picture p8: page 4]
SHT 4/4 · CHART; HIN; NIN; SNAP; HOLD; AT 90°: HELD BY 172 IN-LB NOTCH

GRAVITY (CLOSING) RIBBON SPRINGS ×2 (OPENING)

CAM DETENT | (CLOSING, 0–15°)
NET ON DOOR

PEAK EFFORT 216 IN-LB ≈ 11 LB AT 20 IN HANDLE

NET CLOSING THRU ENTIRE SNAP ZONE — NO STALL

BARE DOOR PEAKS 735 IN-LB (37 LB AT HANDLE)

DOOR OPENING ANGLE

OFFSET SMOKER — DOOR SPRING-HINGE ASSEMBLY

TORQUE BALANCE VS DOOR ANGLE

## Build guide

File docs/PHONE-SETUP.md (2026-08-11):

# Using Claude Code from Your Phone

Claude Code doesn't run *on* the phone — every session runs in a cloud
container that clones your repo, does the work, and pushes the result back to
GitHub as a branch/pull request. Your phone is just the remote control, so
nothing needs to be installed beyond the Claude app.

## One-time setup

1. Install the **Claude app** (iOS App Store / Google Play) and sign in with
   the same account you use on claude.ai — or just open
   [claude.ai/code](https://claude.ai/code) in your phone's browser.
2. Open the **Code** section of the app (or claude.ai/code).
3. If GitHub isn't connected yet, follow the prompt to install the **Claude
   GitHub App** and grant it access to the repositories you want to work on.
   You can change which repos it can see anytime at
   [github.com/settings/installations](https://github.com/settings/installations).

## Daily use

1. Open Code in the Claude app.
2. Pick a repository (e.g. this one) and type what you want done.
3. Claude works in the cloud — you can lock your phone, switch apps, or come
   back later; the session keeps running.
4. Results arrive as a branch and a draft pull request. Review and merge from
   the **GitHub mobile app** (recommended install) or github.com.

## Creating a new repository

The Claude GitHub integration can read and push to repos you've granted it,
but it is **not allowed to create repositories** on your account — that part
takes about a minute by hand:

1. Go to [github.com/new](https://github.com/new) (works fine in a phone
   browser, or use the GitHub mobile app: **Profile → Repositories → +**).
2. Name it, choose **Private**, tick **Add a README file** (so it isn't
   empty), and create it.
3. Grant the Claude GitHub App access to it at
   [github.com/settings/installations](https://github.com/settings/installations)
   → Claude → Repository access → **Select repositories** → add the new repo.
4. It now shows up in the repo picker at claude.ai/code — start a session and
   go.

## Tips

- One repo can hold many unrelated projects (this repo already mixes smoker
  hardware and other work), but separate repos keep history and PRs cleaner.
- Claude pushes to `claude/...` branches and opens draft PRs — nothing lands
  on your default branch until you merge it.
- You can ask Claude to keep watching a PR ("babysit this PR") and it will
  react to CI failures and review comments on its own.

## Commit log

2026-07-04 Add door spring-hinge design: cam snap-close + ribbon spring lift assist
    Design package for the smoker main-door hinge: snap cam with detent
    valley for positive closing, twin coiled-ribbon power springs for lift
    assist, all hardware outboard behind a heat shield. Includes full
    design doc with torque analysis, four generated blueprint sheets, a
    parametric sizing calculator, and the SVG generator script.
    Claude-Session: https://claude.ai/code/session_01XdyuQ3h2yLwUiE1hPhk6mB
2026-07-06 Add waterjet fab print for 24in perforated airflow plate
    Numerically optimized hole pattern: sweep over hole diameters with
    spacing locked at 1.333xD found the optimum at D=2.000 (60 holes,
    4 staggered rows 24/18/12/6, 188.5 sq in open = 41.7%). All-pairs
    spacing, edge margin, and hub clearance verified. Includes production
    SVG/PDF print, cut-ready DXF (CUT + REF layers), generator script,
    and optimization record.
    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
    [plate-24-perforated.dxf]
2026-07-06 Rev B: redesign perforated plate as two-plate rotary damper
    Design review correction: the plate is one of two identical stacked
    plates, one rotating, forming a rotary damper. Rev A spacing (1.333xD)
    could never shut off. Rev B: web = 1.5x hole dia (c-c 2.5xD), same
    hole count per row so all rows seal at one twist angle with monotonic
    flow. Optimized: 18x O1.740 on 9 spokes x 2 rows, full shutoff at 20
    deg twist, 0.441 min seal cover verified all pairs, 42.8 sq in open.
    Print gains closed-position overlay inset and damper operation notes;
    optimization record rewritten with the architecture trade study.
    Claude-Session: https://claude.ai/c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
    [plate-24-perforated.dxf]
2026-07-06 Rev C: enlarge outer damper row to O4.600 (2.6x), per-row diameters
    Review direction: first-row holes 2-3x larger, OD-to-hole gap 0.500
    min. Same count per row (5 spokes) keeps single-angle shutoff and
    monotonic flow while each row carries its own diameter sized to its
    radius. Row 1: 5x O4.600 at R9.200 (edge gap exactly 0.500); row 2:
    5x O1.700 at R3.500. Full shutoff at 36 deg twist, 0.463 min seal
    cover verified all pairs, open area 94.4 sq in (2.2x Rev B).
    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
    [plate-24-perforated.dxf]
2026-07-06 Rev D: OD-to-hole gap scales with hole size (0.5x row-1 dia)
    Review correction: the gap between plate OD and the first row of
    holes is 0.5x the hole diameter minimum, not a flat 0.500. Row 1
    re-solves to 5x O4.000 at R8.000 (gap exactly 2.000); row 2 to
    5x O1.500 at R3.000. Shutoff at 36 deg twist, 0.354 min seal cover
    verified all pairs, open area 71.7 sq in (15.8%).
    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
    [plate-24-perforated.dxf]
2026-07-06 Rev E: add O0.500 center pivot hole for bolt/axle
    Both identical plates get a half-inch thru hole at center for the
    pivot bolt. Filled by the bolt, so no leak path; hub otherwise solid.
    Added to print (view, table, inset, notes) and DXF CUT layer.
    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
    [plate-24-perforated.dxf]
2026-07-06 Add 24in pizza cooking plate: print, single-contour DXF, STL
    One monolithic O24.000 major-OD x 1.000 thick A36 plate relieved to
    O23.000 minor OD between eight 1.000-wide weld islands (45 deg eq sp).
    Openings are full-thickness thru cuts, 0.500 radial depth, R.250
    internal corners; islands are the only weld attachment points.
    Parametric generator emits the five-view fabrication print (top/
    section/isometric/detail/edge development + summary table), a DXF
    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
    [pizza-plate-24.dxf, pizza-plate-24.stl]
2026-07-06 Fix pizza plate detail/development views: no false raised surfaces
    Review feedback: the straightened detail and edge development read as
    raised bosses on the flat disc face. Redrawn: Detail B is a true-
    curvature plan zoom of the actual outline (islands are in-plane
    outline features), and the development now pairs the plan profile
    with a plain edge elevation showing constant 1.000 thickness.
    Geometry, DXF, and STL unchanged.
    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
2026-08-11 Add ZC Mail Sender: Graph app-only outbound email API
    Send-email service so Claude sessions can send mail as
    ahall@zombiecomponents.com through an authenticated endpoint, per the
    2026-08-10 handoff (Path B). The hosted M365 connector's mail-write
    scope was re-tested and still fails with 403 ErrorAccessDenied, so the
    client-credentials daemon flow is the way forward.
    - POST /api/v1/email/send, X-API-Key auth (keyid:secret pairs)
    - FROM hardcoded server-side; unknown fields (incl. attachments) rejected
    - Hourly send cap (file-backed rolling window) and recipient cap
    - Graph error mapping: token_error / permission_error / rate_limited /
    graph_unavailable, with single retries where the spec c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
